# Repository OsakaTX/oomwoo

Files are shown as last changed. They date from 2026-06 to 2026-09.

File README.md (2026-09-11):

<div align="center">

# OOMWOO

*Open-source robot vacuum you build yourself*

Clean well · Hackable · Raspberry Pi · 3D printed · Local / No cloud required · Home Assistant · Arduino · ROS2 · ESP32




</div>

OOMWOO is an *open-source home robot vacuum* you can build yourself, built using
Raspberry Pi, 3D-printing, Home Assistant, Arduino and ROS2. It uses an
affordable 2D LiDAR to map your home and navigate on its own. Local, no
cloud required for regular functionality, no vendor lock-in. Follow us building in public
[Discord](https://discord.gg/3y2JKz5T25) | [X](https://x.com/@0OMWO0) | [Instagram](https://www.instagram.com/oomw0o/) | [Facebook](https://www.facebook.com/profile.php?id=61591466775035) | [Reddit](https://www.reddit.com/r/oomwoo/) | [newsletter](https://stats.sender.net/forms/bo2rAK/view) | [YouTube](https://www.youtube.com/@makerspet) | [oomwoo.com](https://oomwoo.com/) | [Tutorials](https://makerspet.com/learn/)

> Early [build instructions](docs/BUILD_INSTRUCTIONS.md) will be available in Fall 2026.

Reference design images - this is approximately how the finished design will look:

Reference robot vacuum cleaner top
Reference robot vacuum cleaner bottom
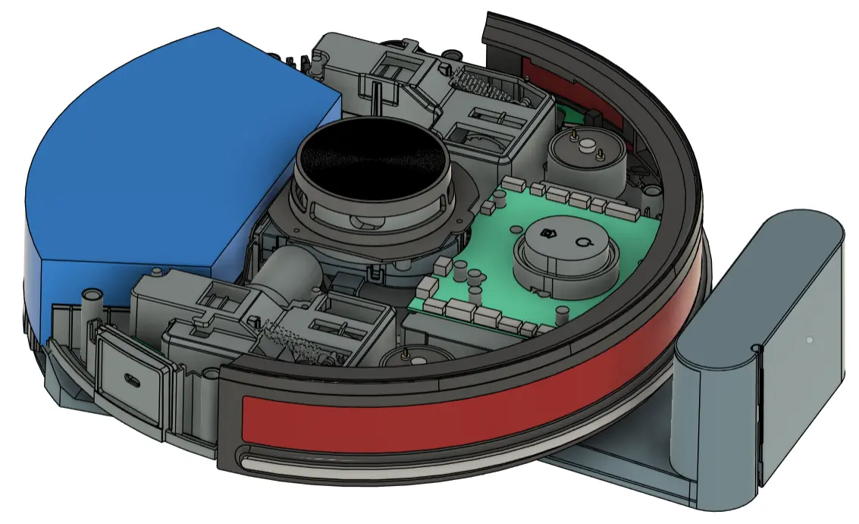
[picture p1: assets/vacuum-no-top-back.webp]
Reference robot vacuum cleaner - top cover removed


## Goals

- Affordable, fully open hardware, software and firmware
- Home appliance product quality - not a throwaway build
- Easy to build, with step-by-step zero-to-hero instructions
- 2D LiDAR mapping and autonomous navigation (ROS2 / Nav2)
- Native Home Assistant integration for local control
- 3D-printable, documented, and hackable chassis
- Buildable from parts you source yourself
- Local, no cloud required for regular functionality
- Optional extra functionality when connected cloud
- Apps on top of ROS2 to customize vacuum operation
- Stretch goal: App store
- Stretch goal: LeRobot integration, OpenClaw

*v0 target: bare-bones build:*

- 3D-printed chassis ([browse](https://github.com/makerspet/oomwoo-install))
- ROS2 Gazebo sim ([install](https://github.com/makerspet/oomwoo-install))
- Basic cleaning, mapping
- Raspberry Pi CM4/CM5 running ROS2 ([install](https://github.com/makerspet/oomwoo-install))

Open Source Deliverables:

- [x] [Software development environment](https://github.com/makerspet/oomwoo-install), robot [description package](https://github.com/makerspet/oomwoo-one/) and [tutorials](https://makerspet.com/blog/simulate-oomwoo-one-robot-vacuum-in-gazebo-with-ros-2/) (ROS2)
- [x] Placeholder real [vacuum cleaner](https://github.com/makerspet/proscenic-m6pro) and [tutorials](https://makerspet.com/blog/tutorial-connect-robot-vacuum-cleaner-to-ros-2-proscenic-m6-pro/) (temporary while OOMWOO is being designed)
- [x] [Bill of materials (BoM)](BOM.md) (rough version available)
- [x] 3D-scanned [sourced parts](https://github.com/makerspet/oomwoo-one-cad/tree/main/lib)
- [ ] 3D-printable [files](https://github.com/makerspet/oomwoo-one-cad)
- [ ] Raspberry Pi [software](https://github.com/makerspet/oomwoo-install)
- [ ] Motor drivers, sensors [PCB boards](https://github.com/makerspet/oomwoo-pcb)
- [ ] I/O PCB [firmware](https://github.com/makerspet/oomwoo-io-firmware)
- [ ] Build, setup, bringup and troubleshooting [instructions](docs/BUILD_INSTRUCTIONS.md)
- [ ] Demo video(s)

## Contributing

Would you like to contribute? See [CONTRIBUTING](docs/CONTRIBUTING.md) for the full guide.

OOMWOO is organized to built by the community, massively *in parallel*.
The vacuum and its software are subdivided into [modules](contributions/README.md), listed on the RFC board.

A volunteer picks whatever module she wants and works on it whenever she wants.
For *code and simulation* modules she builds her package in her *own repo* and sends
a short PR *linking* it from the module; for *docs and specs* she contributes files
in-tree under `contributions/module-name/<her-github-username>`. See
[CONTRIBUTING](docs/CONTRIBUTING.md) for how this works.

Multiple developers are welcome to work on the same module.
The best solution for each module surfaces over time, with the project master having the last call.

1. Pick a contribution from the [RFC board](contributions/README.md).
2. [Let us know](https://github.com/makerspet/oomwoo/discussions) you're working on it and your progress.
3. Check [ARCHITECTURE.md](docs/ARCHITECTURE.md) and
   [SOFTWARE_INTERFACES.md](docs/SOFTWARE_INTERFACES.md) for the system design
   and ROS2 interfaces.

## Requests for Contributions

Every module below is *actionable now* — build it against the Gazebo simulation
([oomwoo-one](https://github.com/makerspet/oomwoo-one)) or a real *placeholder robot*
(a [Proscenic M6 Pro connected to ROS2](https://makerspet.com/blog/tutorial-connect-robot-vacuum-cleaner-to-ros-2-proscenic-m6-pro/)),
until OOMWOO hardware is ready. Pick one, tell us in
[Discussions](https://github.com/makerspet/oomwoo/discussions), build it in your own
repo (docs and specs go in-tree), and send a short PR linking it from the module.

Every RFC — software, firmware, hardware and procurement — lives on the
**[RFC board](contributions/README.md)**, together with its current progress and
status. That board is the single source of truth, so this page links to it rather
than copying it: a second copy here only ever drifts out of date. Broadly:

- **Software & simulation** — cleaning, localization & navigation, perception, the Gazebo sim
- **Firmware & electronics** — STM32 I/O board firmware, the I/O + motor-driver PCB, the board interface
- **Mechanical & procurement** — brushes, blower fan, dust bin, part specs and STEP models

**[→ Browse the RFC board and pick a module](contributions/README.md)**

> Planned and on-hold modules (mechanical design, later-phase software) live in the
> [RFC backlog](docs/RFC_BACKLOG.md).

## Source code reference

- [OOMWOO ROS2 and Ubuntu installation](https://github.com/makerspet/oomwoo-install/) source code
- [OOMWOO ROS2 URDF package and config](https://github.com/makerspet/oomwoo_urdf/) source code
- [remakeai reference vacuum teardown](https://github.com/remakeai/vacuum_cleaner_teardown) — a consumer LiDAR vacuum with a basic dock and stationary mop.

## Related prior art

- [Valetudo](https://github.com/Hypfer/Valetudo) — cloud-free firmware replacement for commercial vacuums (local app-level control, not ROS2)
- [codetiger/VacuumTiger](https://github.com/codetiger/VacuumTiger) - 3irobotix CRL-200-based vacuum low-level control reverse engineered
- [kaiaai/LDS](https://github.com/kaiaai/LDS), [kaiaai/lds2d](https://github.com/kaiaai/lds2d) — open-source 2D LiDAR libraries (C++, Python) supporting 23+ LiDAR models
- [remakeai/vacuum_ros2_bridge](https://github.com/remakeai/vacuum_ros2_bridge) — ROS2 bridge for a 3irobotix CRL-200-based vacuum (Proscenic), full ROS2 control
- [Dennis Giese / robotinfo.dev](https://robotinfo.dev) — teardowns and rootability of commercial robot vacuums.
- [Build a ROS2/LiDAR robot crash course](https://makerspet.com/blog/build-arduino-self-driving-robot-video-instructions/) - watch this if you have no robotics experience
- [Open Mower](openmower.de) - open-source outdoor lawn mower
- [AlieksieievYurii/vacuum-cleaner](https://github.com/AlieksieievYurii/vacuum-cleaner) — a DIY 3D-printed robot vacuum (Raspberry
  Pi Zero W, gyroscope-based, Fusion 360, Android control app, no dock)

## User requirements &amp; Design research

Anecdotal prospective user requirements - collected mostly in [r/RobotVacuums](https://www.reddit.com/r/RobotVacuums/), [r/ROS](https://www.reddit.com/r/ROS/) and as [announcement post](https://makerspet.com/blog/building-an-open-source-robot-vacuum-meet-oomwoo/) comments:

- open-source
- 3D printed first
- cleans well, a first-class appliance, not a throwaway build
  - never gets stuck
  - hair tangle-free
  - modern capabilities - no legacy drag mop; dual-spinning rotary mop or better/roller
  - bagless
- hackable, DIY fixable, upgrade-able
  - examples: vacuum-only version, mop-only version
  - Raspberry Pi
  - Home Assistant integration
- operates without cloud
- later: ability to retrofit existing legacy vacuum cleaner robots

## About

The project name "OOMWOO" is a rotational ambigram - it reads the same flipped 180°, like the robot itself, roaming your floor in every direction.

The project is sponsored by makerspet.com and remake.ai. We are reusing their open-source solutions.
- If you'd rather skip the parts hunt, a kit (motors, PCB, brushes, gaskets, LiDAR) will be available at [makerspet.com](https://makerspet.com), from the same maker behind this project. The kit is a convenience, never a requirement. *Everything here stays open.*
- When we get to apps, [remake.ai](https://remake.ai) will be providing its robot apps platform and app store. Using the app store will be entirely optional. The vacuum will *always support cloud-free, local operation for regular functionality out-of-the-box*. 

## License

Code is released under the [Apache License 2.0](LICENSE).

Hardware design files, once added, to be released under an open hardware
license (TBD).

<!-- Self-hosted star history (auto-refreshed by .github/workflows/star-history.yml).
     No third-party embed / sealed token to expire. -->
<picture>
  <source media="(prefers-color-scheme: dark)" srcset=".github/assets/star-history-dark.svg" />
  <source media="(prefers-color-scheme: light)" srcset=".github/assets/star-history-light.svg" />
  OOMWOO star history
</picture>

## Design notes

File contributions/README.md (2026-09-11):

# OOMWOO Contributions — RFC board

Each folder here is a **Request for Contribution (RFC)** — a self-contained module
(software, firmware, hardware, or procurement) you can pick up and build. Submit
your work under `contributions/<rfc>/<your-github-username>/`. New here? Read
[CONTRIBUTING](../docs/CONTRIBUTING.md), and see the
[RFC lifecycle](../docs/CONTRIBUTING.md#rfc-lifecycle) for how RFCs progress and
retire.

**Status legend** — *Active:* `exploratory` → `ready to start work` /
`design-first` → `in progress`. *Retired* (closed to new contributions, but
**kept in place** for provenance): `completed` · `superseded` · `descoped` ·
`merged`.

**This board is canonical** for every RFC's status and progress. An RFC's own
README describes its scope and how to get started; where its `> Status —` line
disagrees with the row below, the row below wins. Update this board when you land
work.

**Progress** is a rough, self-reported percentage of the RFC's scope — a sense of
"how much is left", not a promise:
 nearly there ·
 under way ·
 barely started / open.

| RFC | What it is | Progress | Status |
|-----|---|:---:|---|
| [clean-and-map](clean-and-map) | First clean: coverage + SLAM + exploration |  | coverage meter + regression harness + drive-to-goal cleaning; coverage-while-mapping not started |
| [nav-localize](nav-localize) | Localization & navigation on a known map |  | AMCL to slam_toolbox (~3x accuracy), custom lost-detection + Cartographer-style global relocalizer (96/96 in sim), stress-tested; needs real-robot validation |
| [floor-care](floor-care) | Wall/edge following, surfaces, mop lift |  | LiDAR contour follower v1 follows walls and concave/convex boundaries (line-fit surface estimate replaced nearest-beam: 0.5 deg vs +-20 deg bearing error); bump-out wall clean; side ToF sensors, mop + FlexiArm modules modelled; loop-closure and bumper handoff still open |
| [cleaning-jobs](cleaning-jobs) | Cleaning modes, zones, job orchestration |  | ready to start work |
| [recovery-safety](recovery-safety) | Recovery behaviors & safety |  | lost-detect to relocalize recovery + one escape reflex; recovery ladder, e-stop, reporting open |
| [dock-cycle](dock-cycle) | Undock, dock, recharge & station services |  | dock mechanical design started; two docks modelled in sim (basic charging pad + auto-empty/mop-wash), manual undocking demoed; teardown, schematic, sensors + fans sourced; docking behaviours not started |
| [obstacle-avoidance](obstacle-avoidance) | Near-field camera + ToF avoidance |  | front ToF + stereo modelled in sim, transient-obstacle detection demoed, scan rays marked static/dynamic for downstream ML |
| [control-app](control-app) | Control app & UX |  | ready to start work (design track) |
| [live-robot-bringup](live-robot-bringup) | Live robot bring-up & validation |  | Proscenic M6 Pro to ROS2 tutorials; 3irobotix Delta-2C Pro LiDAR driver implemented and validated |
| [health-monitor](health-monitor) | Stack health monitor & software watchdog |  | design-first: contracts drafted, ready to start |
| [compute-benchmark](compute-benchmark) | Compute benchmark & memory reduction |  | tentatively fits 2 GB Pi CM4/CM5; an old smartphone is now a supported compute option (no Pi needed); repeatable Pi benchmark CLI + guide |
| [mcu-io-firmware](mcu-io-firmware) | MCU I/O board firmware (STM32G473) |  | host-tested framing/safety prototypes + simulated CPU/MCU loop; real STM32 HAL, motor and safety bring-up open |
| [io-board-interface](io-board-interface) | I/O board software interface |  | SPEC.md (GPIO/pinout contract) drafted; ROS2 bridge mapping + validation open |
| [urdf-gazebo-sim](urdf-gazebo-sim) | oomwoo URDF + Gazebo simulation |  | sim model essentially complete: full sensor suite, living-room + kitchen worlds, docks, GPU rendering |
| [mac-dev-env](mac-dev-env) | macOS (Apple Silicon) dev environment (pixi) |  | initial working pixi recipe (experimental) |
| [io-pcb](io-pcb) | I/O + motor-driver PCB (KiCad) |  | smartphone-as-compute option designed; schematic ~50% hand-checked (first review round); carpet sensor driver; drive wheels brought up on the bench; front + side sensor boards, watchdog + motor shutoff, charging dock; not validated, do not fabricate |
| [dust-bin](dust-bin) | Dust bin (mechanical module) |  | base port added to the chassis CAD; bin design still ahead |
| [vacuum-fan](vacuum-fan) | Blower fan assembly (mechanical module) |  | suction fan digitized to STEP, fans sourced and ordered, main fan brought up on the bench |
| [part-specs](part-specs) | Procure part specs & datasheets |  | drive-wheel and 4 suction-fan pinouts, voltages and no-load/stall currents confirmed by measurement; cliff/bumper/wheel pinouts reverse-engineered; dock fans, PSU, dock sensors, micro-switches, mop disk, VL6180 sourced |
| [source-3d-models](source-3d-models) | Source 3D models (STEP) for BOM parts |  | parts scanning mostly complete: battery, brushes, wheels, mop/FlexiArm, fan, carpet sensor, camera, switches |
| [stair-climbing](stair-climbing) | Multi-floor: stair climbing (drive-in exoskeleton) |  | exploratory, for later |
| [esp32-p4](esp32-p4) | ESP32-P4 experimental compute + safety track |  | exploratory, for later |

> **Two builds.** OOMWOO comes in a *basic* version (vacuum only, simple to
> assemble, charging-only dock) and a *full-featured* one (mop, auto-empty,
> extendable side brush). Some RFCs serve only the full build - mop lift in
> floor-care, the auto-empty dock in dock-cycle - so check which you are
> targeting before you start.

> **Core mechanical design is not an RFC.** The chassis, brushes, mop, wheel
> mounts and shell are designed in-house and tracked in
> [oomwoo-one-cad](https://github.com/makerspet/oomwoo-one-cad) — a tightly-coupled
> reference design is slow and messy to settle by consensus. Planned hardware
> modules are listed in the [RFC backlog](../docs/RFC_BACKLOG.md); a well-defined,
> standalone piece (a mount, a spec, a part model) graduates to an RFC here.

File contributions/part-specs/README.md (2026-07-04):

# Procure Part Specs & Datasheets for Sourced Components

We've already sourced candidate parts (see [BOM.md](../../BOM.md)). To design the I/O
board and firmware, *drive the motors and fans*, and build accurate mounts, we need each
part's detailed *electrical + mechanical specs* — pinouts, voltages, currents, encoder
PPR, torque, waveforms, etc. Vendors rarely publish these for vacuum sub-assemblies, so
contributors will *find datasheets, ask vendors, or safely reverse-engineer* them.

This is the *electrical/mechanical data* companion to
[source-3d-models](../source-3d-models) (which covers the *geometry*). No robotics
background needed — a multimeter, patience, and (for reverse-engineering) an oscilloscope go far.

Please check [BOM.md](../../BOM.md) and the [sourcing follow-along blog post](https://makerspet.com/blog/how-to-source-bom-for-oomwoo-open-source-vacuum-robot/)
for datasheets/specs already found.

## What we need, per part

### Drive wheel assembly (Roborock-family — see BOM)
- motor model; motor/assembly *datasheet* (if any)
- *encoder type + PPR* (pulses per revolution)
- *gearbox ratio*; *wheel diameter*
- rated + max motor *voltage*, *current* (no-load & stall), *torque*
- max / rated wheel *speed*
- *cable length(s)*; *connector models* (both ends); *full connector + motor pinouts*
- *wheel-drop sensor* model + pinout (these modules include one)
- signal *waveforms* (encoder channels, motor drive)
- assembly *weight*

### Suction fan / blower (several options sourced — see BOM)
- fan/motor model; *datasheet*
- rated *voltage, current, RPM*; *airflow* + *static pressure (Pa)*
- *how to drive it* — BLDC driver + control interface (PWM / tach / hall / 3-phase),
  soft-start / protection behaviour
- *connector model(s) + pinout*; cable length
- signal *waveforms*
- *weight*

### Caster / universal wheel assembly (Roomba-family — see BOM)
- model, dimensions, mounting, any embedded sensor, weight, datasheet

## Already found vs still missing 

*Found*
- *Fan datasheet (some options):* https://file.elecfans.com/web1/M00/CC/89/o4YBAF-ZOBKAQBvyADDMAglsvTw020.pdf
- *Nidec BLDC motors* (candidate fan motors — *bare motors, not the full suction assemblies*):
  [NCJ-20N Type-3](https://www.nidec.com/en/product/search/category/B101/M102/S100/NCJ-20N-Type-3/),
  [NCJ-20N Type-4](https://www.nidec.com/en/product/search/category/B101/M102/S100/NCJ-20N-Type-4/)
- *Driving the fans:* [ripinteer/fan_protector](https://github.com/ripinteer/fan_protector)
  — reference for driving / protecting the BLDC blower (from earlier project research)

*Still missing (help wanted)*
- Connector *pinouts* + cable lengths for wheels, fans, caster
- *Encoder type + PPR*, gearbox ratios, torque/current under load
- *Wheel-drop sensor* model + pinout
- Signal *waveforms* (encoder, motor/fan drive)
- Suction-*assembly*-level datasheets (we have some bare motors, not the assemblies)
- Weights; caster specs

## Reverse-engineering — only if specs can't be found, and SAFELY

If a spec isn't published, reverse-engineer it by opening an existing vacuum and probing.
*Safety first:*
- Don't do it unless you're qualified, experienced.
- Opening a vacuum usually *voids the warranty* and *can damage it* — accept that risk knowingly.
- *Secure / prop up the vacuum* so it can't scoot off the table or bench when the wheels or
  fan spin during testing (clamp it, or raise the wheels off the surface).
- Respect the *Li-ion battery* — don't short, pierce, or stress the pack; disconnect where sensible.
- Mind *pinch points and spinning parts* — keep fingers/hair clear of the impeller and brushes.
- Any *mains-connected* testing (e.g. a dock) — extra caution; isolate.
- Use a *multimeter + oscilloscope* to capture voltages, currents, and waveforms; trace and
  *label connector pinouts*; photograph everything.

*Legal:*
- By performing any work for this project including reverse engineering you agree to
  - wave liability, indemnify this project, the legal entity behind it (Remake AI Statutory Trust) and and its founder
  - contribute your work and results thereof, if any, as open-source, to be published under Apache 2.0 license

## Submit

A PR to `contributions/part-specs/<your-github-username>/<part>/`:
- a spec sheet (markdown table) with everything you found
- any datasheets (PDF) and source links
- photos of connectors + labelled pinouts
- waveform captures where reverse-engineered
- provenance — which vendor / model / revision the data is from
- announce it in [Project Discussions](https://github.com/makerspet/oomwoo/discussions?discussions_q=)

## Acceptance criteria

- Spec sheet for a part (or a clearly-scoped subset)
- Datasheets / links where found
  - pinouts + waveforms where reverse-engineered when appropriate
- Provenance stated (part / vendor / revision)
- Verifiable by someone else with the same part
- TBD, expect criteria to evolve

The maintainer selects among compliant candidates using these criteria. Multiple attempts
are welcome and useful even if not selected — a non-selected spec sheet is still a valid
reference and a fallback.

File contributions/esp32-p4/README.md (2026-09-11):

# ESP32-P4 (experimental compute + safety track)

A home for **ESP32-P4** experiments on OOMWOO: can a ~$4 dual-core RISC-V MCU
with 32 MB in-package PSRAM run onboard 2D SLAM, and what safety architecture
would a P4-based robot need? This is an **alternative compute path**, deliberately
separate from the consumer ROS 2 profile — see
[compute-benchmark](../compute-benchmark) for the Pi 4 / CM4 onboard-ROS 2 work.

> **Status — exploratory.** A *bounded feasibility experiment*, not a committed
> direction. The goal is a measured yes/no, not a port. Develop against a
> recorded dataset and the official Espressif dev board; coordinate in
> [issue #18](https://github.com/makerspet/oomwoo/issues/18) and the
> [discussions](https://github.com/makerspet/oomwoo/discussions).

## Why P4 is interesting

- **Cheap and capable-ish.** ESP32-P4: dual 400 MHz RISC-V HP cores + a 40 MHz
  LP core, up to **32 MB in-package PSRAM**, ~**$4** including the PSRAM.
- **Storage + I/O.** UHS-I 4-lane SDIO (fast SD/eMMC — a large map could be paged
  into PSRAM by region), dedicated CSI camera and DSI display pins *outside* the
  GPIO range, and a hardware H.264 encoder (up to 1080p/30) that can consume the
  CSI stream with little CPU load.
- **Pairs with a radio coprocessor.** ESP32-C5/C6 for Wi-Fi/BLE and 802.15.4
  (Matter over Thread).

## Why it is *not* a drop-in for the consumer profile

- **No NPU.** Modern vacuums lean on an NPU for real-time camera-based obstacle
  avoidance / object recognition; the P4 has none. (It can run small NNs in
  software with AI-acceleration instructions — e.g. a pedestrian-detection demo —
  but that is not an NPU.) OOMWOO's current vision plan is **two OV5647 stereo
  NIR wide-FoV cameras** (stereo depth + object recognition) — exactly the
  real-time workload an NPU normally accelerates, so whether the P4 can carry it
  is an open question (below).
- **Not enough GPIO for the MCU role.** The base controller needs 50+ GPIO (see
  the tentative pin list in issue #18). A TCA9554-class I²C IO expander adds
  *slow* binary in/out only; PWM, encoders, and fast interfaces must stay on a
  real MCU.
- **PSRAM is not free RAM.** Espressif's docs note accesses larger than the cache
  fall back to PSRAM speed, and task stacks live in internal RAM by default — so
  both *capacity* and *effective real-time bandwidth* must be measured, not
  assumed.
- **Hackability.** OOMWOO declares ROS 2 support so SLAM/nav is hackable to
  ~1.3M ROS 2 users; a native ESP-IDF SLAM firmware is hackable to ESP32 firmware
  specialists only. A P4 SLAM firmware is an *option*, not the official path.

## The bounded experiment

Prove or disprove "P4 can run onboard 2D SLAM" with one apples-to-apples test —
**do not port ROS 2 / Nav2 first**:

1. **Record one dataset** — LiDAR (5 Hz) + odometry, from the sim or the
   [placeholder Proscenic M6 Pro](https://makerspet.com/blog/tutorial-connect-robot-vacuum-cleaner-to-ros-2-proscenic-m6-pro/).
2. **Replay it two ways** — Pi 4 / CM4 with `slam_toolbox`, and the P4 with a
   *minimal native ESP-IDF 2D SLAM* prototype.
3. **Measure** against a fixed budget:
   - **~200 ms per scan** (5 Hz, no scan dropping);
   - **closes the loop within 32 MB PSRAM** without pathological fragmentation;
   - effective PSRAM bandwidth under cache-miss fallback; internal-RAM stack
     headroom.
4. **Use the official [ESP32-P4X-Function-EV-Board]** so silicon + memory config
   are explicit. Note the **"X"**: the board uses the **ESP32-P4NRW32X** die,
   recommended for new designs; many 3rd-party boards ship the non-"X"
   (older-revision) part.

**Pass** → the P4 earns a deeper prototype. **Fail** → the same dataset gives a
useful lower bound and reinforces the micro-ROS / offboard *educational* profile
without speculation.

## Safety architecture (ADR — to be written)

A P4 is a high-level compute module; it must **not** be in the hard-stop chain.
The direction from the thread is a layered, fail-low design:

1. **External hardware gate / window watchdog** — the final motor-power cutoff.
   Motor enable defaults **OFF** and requires a valid *periodic* signal; the
   passive electrical state (external pull-down / latch) means **stop**, so an
   unpowered or reset system cannot authorize motion.
2. **STM32G473 base controller** (selected) — owns wheel/brush
   PWM, encoders, current sensing, bumper/cliff/wheel-drop, charging supervision,
   and deterministic stop. It services the hardware gate *only* while its full
   safety state is valid. These functions can't be replaced by a gate IC without
   recreating them as a large discrete circuit.
3. **ESP32-P4** — SLAM / navigation / high-level behavior. Its **LP core** may
   monitor an HP heartbeat in shared/LP SRAM and assert a dedicated fail-low
   **`P4_HEALTHY`** line (and reset the HP cores), improving diagnostics — but it
   is *optional* to the hard-stop chain and never issues motor commands.

Related, separate milestone — **OTA update of the safety MCU** (later, after the
hard-stop and base-control firmware are bench-validated): the P4 can drive
`BOOT0` / `nRESET` into the STM32 factory ROM bootloader (AN2606 / AN3155 USART,
or USB DFU), so end users need no ST-Link or STM32 SDK. It must be gated by a
signed, version-checked, immutable STM32 boot stage; motors + charging forced OFF
throughout; dual-bank staging with rollback; and the P4 must not be able to
bypass signature verification. `esp-serial-flasher` is useful host/target prior
art but speaks Espressif ROM protocols, so it needs a separate STM32 backend.

## Open questions

- **Can the P4 perform real-time obstacle avoidance?** OOMWOO plans **two OV5647
  stereo NIR wide-FoV cameras** — stereo depth + object recognition at frame
  rate is the workload that normally needs an NPU/SoC. Can the P4's dual RISC-V
  cores + software AI-acceleration path meet it, or does obstacle avoidance stay
  off the P4 (host-side, or a separate accelerator)? Two OV5647s also need two
  CSI streams (dual-camera interface or a mux) — worth confirming on the P4X.
- Does a minimal native ESP-IDF SLAM meet the 200 ms / 32 MB budget at all?
- Is the LP core enough isolation, or is a dedicated hardware-gate IC still
  required as the final cutoff? (Leaning: keep the external gate regardless.)
- The current drive wheels are brushed DC motors controlled by STM32-owned
  H-bridges. The P4 must never run wheel PWM/H-bridge control or become part of the
  motor-stop path; its loss only removes high-level commands, while the STM32 and
  external watchdog force the safe state.

## Request for contribution

Add your work under your GitHub username:

```text
contributions/esp32-p4/<your-github-username>/
```

Keep native-SLAM prototypes, board bring-up notes, measurements, and the safety
ADR here. Coordinate scope in
[issue #18](https://github.com/makerspet/oomwoo/issues/18) so tracks don't overlap
with [compute-benchmark](../compute-benchmark),
[recovery-safety](../recovery-safety), or the I/O board work
([io-board-interface](../io-board-interface), [mcu-io-firmware](../mcu-io-firmware)).

[ESP32-P4X-Function-EV-Board]: https://docs.espressif.com/projects/esp-dev-kits/en/latest/esp32p4/esp32-p4x-function-ev-board/index.html

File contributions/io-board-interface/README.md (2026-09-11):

# I/O Board Software Interface

The I/O board is where OOMWOO's ROS2 software meets the real robot: wheel
drivers, cleaning motors, cliff sensors, bumper sensors, dock sensing, power
state, battery charging, and the MCU watchdog.

This contribution area is for the CPU-to-MCU software contract that sits between
the Raspberry Pi Compute Module and the STM32 I/O board firmware.

## Why this matters

The hardware can move quickly only if the firmware and ROS2 work have a stable
interface to build against. The goal is to define the contract before the board
is fully frozen:

- which signals are owned by the MCU vs the CPU
- what commands the CPU can send to the MCU
- what telemetry the MCU publishes back
- what always stays safety-critical and independent of Linux/ROS2
- how the ROS2 hardware bridge maps serial frames into standard ROS topics
- how to validate the contract in simulation, with loopback tests, then on real
  hardware

## Scope

Included:

- CPU-to-MCU serial protocol proposals
- ROS2 topic/service/action mapping for the hardware bridge
- safety and watchdog behavior
- signal ownership tables tied back to the I/O board schematic and part specs
- simulators, parsers, replay tools, and tests that make the protocol
  reproducible

Not included:

- final STM32 firmware implementation
- final PCB layout decisions
- Linux kernel drivers
- app/cloud/Home Assistant UI

## References

- [I/O + motor-driver PCB RFC](../io-pcb)
- [I/O board repository](https://github.com/makerspet/oomwoo-pcb)
- [Architecture: CPU/MCU split](../../docs/ARCHITECTURE.md)
- [ROS2 software interfaces](../../docs/SOFTWARE_INTERFACES.md)
- [Part specs](../part-specs)

## Submit

A PR to `contributions/io-board-interface/<your-github-username>/` should include:

- a short README explaining the proposed contract
- protocol docs or schemas
- a mapping from hardware signals to ROS2 topics/services
- testable tooling where possible
- known open decisions that need maintainer or PCB-designer input

## Acceptance criteria

- The contract is versioned and can evolve without breaking old frames silently.
- Stale motion commands fail safe.
- MCU-owned safety events do not depend on ROS2 being alive.
- Message rates and payload sizes are realistic for the chosen serial link.
- The proposal links back to current hardware references and calls out conflicts
  instead of hiding them.
- At least the framing/parser pieces are testable without hardware.

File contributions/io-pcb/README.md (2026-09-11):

# I/O + Motor-Driver PCB (hardware / KiCad)

The custom [I/O board](https://github.com/makerspet/oomwoo-pcb) that
connects every OOMWOO motor and sensor to the SBC: an STM32 MCU,
motor drivers, sensor front-ends, and battery charging on one PCB. Proposed
software-interface contract: the MCU runs safety-critical firmware and talks to
the CM4/CM5 CPU over a custom serial / USB link.

> *Draft design basis:* OOMWOO v1 uses a *CM4/CM5-style CPU module* for ROS2, Nav2, SLAM,
> so this board is an *I/O + power carrier* — no soldered application processor on it. There is a
> starting-point Kicad schematic and [SPEC.md](https://github.com/makerspet/oomwoo-pcb/blob/main/docs/SPEC.md).

# References

- *Board spec (authoritative, most up-to-date)* —
  [oomwoo-pcb](https://github.com/makerspet/oomwoo-pcb) ·
  [SPEC.md](https://github.com/makerspet/oomwoo-pcb/blob/main/docs/SPEC.md).
  The current MCU (**STM32G473VCT6**), motors, sensors, charging, and GPIO budget live here;
  this RFC is the request-for-contribution, the SPEC is the truth.
- *MCU firmware* — [mcu-io-firmware RFC](../mcu-io-firmware) ·
  [oomwoo-io-firmware](https://github.com/makerspet/oomwoo-io-firmware).
- *Starting-point schematic (PDF)* —
  [makerspet/oomwoo-pcb](https://github.com/makerspet/oomwoo-pcb/blob/main/docs/oomwoo-io-board-RK3562-schematic.pdf).
  An STM32G070 reference (Apache-2.0, *unvalidated* — a starting point, not a proven
  design). Trim it down as described below.
- *Current I/O board repository* —
  [makerspet/oomwoo-pcb](https://github.com/makerspet/oomwoo-pcb), including
  KiCad files and the evolving [SPEC.md](https://github.com/makerspet/oomwoo-pcb/blob/main/docs/SPEC.md).
- *CPU/MCU software interface* —
  [io-board-interface](../io-board-interface) drafts the custom serial contract, ROS2 bridge
  mapping, watchdog behavior, and hardware/software decision ledger.
- *Drive-wheel connector pinout* —
  [AlieksieievYurii vacuum-cleaner motherboard schematic](https://raw.githubusercontent.com/AlieksieievYurii/vacuum-cleaner/2bd7cf7f9af3ae9040373f667bab83e2e57c26b7/motherboard/circuit-pcb/SCHEMATIC_motherboard.svg)
  shows the drive-wheel assembly connectors: *JST PH2.0, 6-pin* —

  | Pin | Signal |
  |---|---|
  | 1 | MOT+ |
  | 2 | MOT- |
  | 3 | HALL_SPEED |
  | 4 | HALL_DIR |
  | 5 | +5V |
  | 6 | GND |

  Verify against the *sourced* Roborock-family wheel module before layout — a submission in
  [part-specs](../part-specs) describes a variant with extra wheel-drop / limit-switch pins,
  while the current OOMWOO I/O board schematic uses a board-side 5-pin signal connector with
  the H-bridge on the I/O board. Confirm the final connector and harness before layout.
- [part-specs](../part-specs) — connector pinouts, encoder PPR, and datasheets for the sourced parts.
- [design-document.md](../../docs/design-document.md) — the I/O-board section (MCU, pin budget,
  offloading the fan to an external ESC, etc.).
- [BOM.md](../../BOM.md) — the sourced parts this board must drive.
- [Project discussions](https://github.com/makerspet/oomwoo/discussions?discussions_q=) · [Discord](https://discord.gg/3y2JKz5T25)

# Request for Contribution — Instructions

Deliver a *KiCad schematic* derived from the reference PDF, trimmed to the I/O side and
updated for OOMWOO, then *hold for review before PCB layout*.

- *Remove the Rockchip subsystem entirely* — the RK3562 SoC and everything that exists only
  to support it: *LPDDR4 DRAM, eMMC, the SoC PMIC / SoC-specific power rails (VCCIO, PMU / OSC
  / PLL), the DDR PHY, the USB / PCIe PHY, and the SoC's MIPI camera interface*. Heavy compute
  and the camera interfaces now come from the *CM4/CM5 module* (whose socket this board adds) —
  the board routes MIPI CSI camera connectors off that socket (see [SPEC](https://github.com/makerspet/oomwoo-pcb/blob/main/docs/SPEC.md)),
  not off a removed SoC.
- *Remove the WiFi / BT module* (AP6256) — WiFi/BT comes from the compute module, or is added
  on the carrier (M.2 / USB) for modules without onboard WiFi (see SPEC).
- *Add a CM4/CM5 socket + support* (adapt the official Raspberry Pi CM4/CM5 IO-board designs)
  so the board is a *carrier* for the compute module; see the [SPEC](https://github.com/makerspet/oomwoo-pcb/blob/main/docs/SPEC.md).
- *Keep and convert to KiCad the I/O side:*
  - *STM32G473VCT6* MCU + support (clock, decoupling, debug / boot, the custom-serial link to the CPU)
  - *motor drivers* — drive wheels (×2), main brush, side brush, water pump, mop lift / spin
    (if fitted); put the *suction fan on an external ESC* (one PWM line) to save MCU pins
  - *sensor front-ends* — cliff / anti-fall IR, docking IR + bumper, side-proximity IR, bumper
    switches, IMU, LiDAR interface, multizone ToF, ultrasonic carpet sensor
  - *battery charging + protection / BMS*, and the board power rails that feed the STM32 /
    sensors / motors (keep these; remove only the SoC-specific rails)
  - speaker + amp, mic, buttons, LEDs
- *Move the battery from 3S to 4S* — OOMWOO targets *~14.8 V* (see [BOM.md](../../BOM.md)). The
  reference appears to be 3S; update the pack, the charge-IC configuration, the protection, and
  any cell-count-dependent dividers / thresholds to *4S*.
- *Reconcile the drive-wheel connectors* with the sourced wheel module and the current
  OOMWOO I/O board KiCad reference before layout; document the final board-side connector,
  harness, motor-power path, encoder pins, and wheel-drop handling.
- assume battery Xiaomi/Roborock/Dreame BRR-2P4S-5200
- *Convert the kept design to KiCad* (from Altium); keep a clean, readable, hierarchical schematic.
- *Hold here for review.* Deliver the trimmed, 4S, KiCad *schematic* and stop — the maintainer
  reviews before anyone starts PCB layout / manufacturing.
- *Submit* a PR to `contributions/io-pcb/<your-github-username>/` with the KiCad project, a short
  sub-BoM, and notes; announce it in [Project Discussions](https://github.com/makerspet/oomwoo/discussions?discussions_q=).
- iterate with review
- TBD, expect the RFC to evolve

## Acceptance criteria (schematic-hold milestone)

- The *entire Rockchip subsystem* (SoC, DRAM, eMMC, PMIC / VCCIO / PMU / PLL, DDR + USB/PCIe
  PHY, MIPI camera) and the *WiFi / BT module* are removed.
- The *kept blocks* (STM32G473, motor drivers, sensor front-ends, battery charging, audio,
  buttons / LEDs, the CM4/CM5 socket + support, and the custom-serial CPU link) are present,
  correct, and complete in *KiCad*.
- Battery as specified
- Drive-wheel connectors are reconciled with the current KiCad reference and part-specs,
  including motor-power path, encoder pins, and wheel-drop handling.
- Delivered as a buildable *KiCad project*; *ERC clean*; a sub-BoM and short design notes included.
- Stops at the reviewed *schematic* — no PCB layout yet.
- Documented and reproducible.
- TBD, expect criteria to evolve.

The maintainer intends to *accelerate* this module and may commission a contributor to do it;
community submissions are still welcome and reviewed the same way. The maintainer selects among
compliant candidates using these criteria — multiple attempts are welcome and useful even if
not selected.

## Appendix A. MCU GPIO budget

The GPIO budget is maintained in the board
[SPEC.md](https://github.com/makerspet/oomwoo-pcb/blob/main/docs/SPEC.md)
(authoritative, and it carries the open TODOs — e.g. the GPIO 36/46 bumper-label question).
It is **not duplicated here**, to avoid the two copies drifting apart.

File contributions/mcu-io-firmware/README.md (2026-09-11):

# MCU I/O Board Firmware (STM32G473 — Arduino + FreeRTOS)

The firmware that runs on the OOMWOO [I/O board](https://github.com/makerspet/oomwoo-pcb)
MCU. In OOMWOO's CPU/MCU split ([ARCHITECTURE.md §5.4](../../docs/ARCHITECTURE.md)),
the *CPU* (CM4/CM5-class module) runs ROS2/Nav2/SLAM, and the *MCU* on the I/O
board owns *motors, encoders, sensors, battery charging, and hard safety*. This
module is that MCU firmware. Its defining constraint: *safety must never depend on
Linux/ROS2* — and, per the architecture below, it must never depend on the friendly
Arduino layer either.

The full design lives in the firmware repo — this RFC is the request for
contribution and the acceptance bar.

> *Status — in progress.* Host-tested framing, safety-policy, simulator, and ROS2
> bridge work now exists, but real STM32 HAL, motor control, ISR integration, IWDG,
> charging, and measured cutoff times remain open. Build hardware milestones on a
> *Nucleo-G474* first; move to the real board when it is fabricated. Coordinate in
> the [firmware discussion](https://github.com/makerspet/oomwoo/discussions/49).

# Important References

- *Firmware repo + full spec* — [makerspet/oomwoo-io-firmware](https://github.com/makerspet/oomwoo-io-firmware).
  The repo README is the detailed architecture, peripheral map, and milestones; read it first.
- *Active implementations* — upstream framing bring-up
  [PR #2](https://github.com/makerspet/oomwoo-io-firmware/pull/2), ISR-owned CPU
  watchdog [PR #3](https://github.com/makerspet/oomwoo-io-firmware/pull/3), and
  [Creative-Dhanush's host-tested firmware/simulator](Creative-Dhanush) with its
  ROS2 bridge. These overlap at the protocol/policy layer; hardware integration
  and maintainer selection of the canonical upstream path are still open.
- *Board spec (authoritative)* — [oomwoo-pcb SPEC.md](https://github.com/makerspet/oomwoo-pcb/blob/main/docs/SPEC.md)
  — the motors, sensors, charging, and GPIO budget the firmware must serve (work in
  progress; note its open TODOs, e.g. the GPIO 36/46 bumper-label question).
- *CPU ↔ MCU serial contract* — [io-board-interface RFC](../io-board-interface) —
  the custom serial framing, command/telemetry set, and health/watchdog handshake.
- *System architecture* — [ARCHITECTURE.md §5.4](../../docs/ARCHITECTURE.md) — the CPU/MCU split and safety rationale.
- *Simulated MCU link* — the [oomwoo-install](https://github.com/makerspet/oomwoo-install)
  serial stub lets the CPU side be developed/tested before the board exists.
- [STM32duino](https://github.com/stm32duino/Arduino_Core_STM32) · [STM32FreeRTOS](https://github.com/stm32duino/STM32FreeRTOS)
- [Project discussions](https://github.com/makerspet/oomwoo/discussions?discussions_q=) · [Discord](https://discord.gg/3y2JKz5T25)

# The architecture, in one rule

Arduino-*or*-real-time-safety is a false choice; we get both by *layering*, so the
layer a contributor touches is not the layer that keeps the robot safe:

- *Layer 3 — Arduino (STM32duino) API:* the contributor-friendly surface where new
  behaviours, features, and peripheral bring-up happen.
- *Layer 2 — FreeRTOS tasks* (static allocation): comms, control, telemetry,
  charging, and safety supervisors; watchdog-fed, bounded reaction times.
- *Layer 1 — HAL/timer-ISR real-time core:* motor control, the hard-safety cutoffs,
  and the CPU watchdog. Maintainer-owned, safety-reviewed.

*The rule:* the safety and motor-control core is *structurally isolated* from the
Arduino layer — a bug or infinite loop in a contributor's sketch *cannot* defeat a
cliff-stop, an overcurrent cutoff, or the CPU watchdog, because those live in
interrupts and a hardware watchdog the upper layers can't starve.

# Request for Contribution — Instructions

Phased bring-up (details and the peripheral map are in the firmware repo README):

- *Blink + SWD + serial echo* on a G473 dev board.
- *CPU serial link* — implement the [io-board-interface](../io-board-interface)
  framing + health/watchdog handshake; loopback tests green.
- *One drive motor, closed loop* — H-bridge PWM + encoder capture + velocity PID in
  the real-time core (the pattern every other motor follows).
- *All actuators* — suction fan (BLDC + FG), main/side brush, LiDAR spin, water
  pump, mop motors/servos — each with current sense.
- *All sensors* — cliff / dock / side-proximity IR (ADC), bumpers, wheel-drop, IMU
  (SPI), current channels.
- *Safety layer* — ISR-level cliff/bumper/wheel-drop stop, per-motor overcurrent
  limiting, IWDG, CPU watchdog/reset; *measure and document* each cutoff's
  worst-case reaction time; include a hazard note.
- *Charging supervisor* — power-path charger control, 0.5C cap, input DPM, graceful
  "insufficient charger" handling.
- *Integration* — run end-to-end against the CPU (or the simulated MCU serial tool).
- Contribute in the firmware repo; announce progress in [Project Discussions](https://github.com/makerspet/oomwoo/discussions?discussions_q=).
- iterate with review
- TBD, expect the RFC to evolve

*Safety-critical code requires maintainer safety review before merge* (over-current,
thermal, short, mechanical pinch — include a hazard note).

## Acceptance criteria

Objective, measurable. Examples:
- *Deterministic real-time core* — measured, documented worst-case reaction time for
  each safety cutoff.
- *Safety is layer-independent* — a deliberately hung Arduino-level task must *not*
  defeat a cliff-stop, overcurrent cutoff, or the CPU watchdog; demonstrate it.
- *Implements the [io-board-interface](../io-board-interface) serial contract* —
  loopback + integration tested.
- *Every actuator and sensor exercised* on the bench, documented, reproducible by
  someone else.
- *Charging behaves per spec* — 0.5C cap held; graceful degradation on a weak charger.
- *Safety-critical code passed maintainer safety review* with a hazard note.
- TBD, expect criteria to evolve.

The maintainer selects among compliant candidates using these criteria. Multiple
attempts are welcome and useful even if not selected — a non-selected design is
still a valid learning exercise and a fallback.

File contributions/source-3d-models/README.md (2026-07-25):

# Source 3D Models (STEP) for Off-the-Shelf BOM Parts (procurement)

To design printed mounts and the chassis that *fit real sourced parts*, we need accurate
3D models (*STEP*) of the off-the-shelf components in the [BOM](../../BOM.md) — the
drive-wheel assembly, the suction fan/blower (several candidate models), the caster wheel,
the side-brush motor, and more. Manufacturers rarely publish these, so the community needs
to *obtain, measure, and model* them. Every printed mount and the chassis references this
geometry — see [ARCHITECTURE.md](../../docs/ARCHITECTURE.md) §5.2 (mechanical interface
standard). Missing models block or force guesswork on the mechanical modules.

This is a great *first contribution* for anyone with CAD skills and calipers — no
robotics or programming needed, and the modules can be modeled *in parallel*.

> *Please check the [STEP models library](https://github.com/makerspet/oomwoo-one-cad/tree/main/lib) before you pick a part.*
> STEP models live in the [makerspet/oomwoo-one-cad](https://github.com/makerspet/oomwoo-one-cad) repo, in the `lib` folder.

# Request for Contribution - Instructions

- *Pick a part* from the [BOM](../../BOM.md) and *claim it* in
  [Project Discussions](https://github.com/makerspet/oomwoo/discussions?discussions_q=) or
  [Discord](https://discord.gg/3y2JKz5T25) so two people don't model the same thing. Post progress too.
  - Please consider submitting a PR (pull request) to `makerspet/oomwoo` in `contributions/source-3d-models/<your-GitHub-username>/README.md`
  with a brief description of which part you have picked, relevant links (to your repo containing the part) and files if any.
- *Get an accurate model* — three paths:
  1. *Find an existing STEP* (manufacturer site, GrabCAD, etc.) and *verify it against the
     real part* (dimensions match). Fastest — but confirm it's the same model/revision.
  2. *Model it yourself*: order the exact part (AliExpress links are in the BOM), measure
     with calipers, optionally use a 3D scanner and build an accurate STEP.
  3. 3D scan the part, convert the mesh into a STEP file. As an example, I use Creality Raptor.
- *Capture the interface-relevant geometry* (external only — internal detail is not needed):
  - Overall *bounding envelope* (so it fits the chassis space / height budget)
  - *Mounting features*: holes, bosses, clips, bolt pattern — and their exact positions
  - *Functional interfaces*: axle/shaft position + axis, wheel contact plane, fan air
    inlet/outlet, connector / wire-exit locations
  - *Mating faces* where other modules attach
  - Note the *key overall dimensions*
- *Record provenance* — the exact vendor + link + which model/revision you measured. Parts
  vary between sellers and revisions; say which one this model represents.
- *Submit a PR* to `contributions/source-3d-models/<your-github-username>/<part-name>/`:
  - the *STEP* file (primary deliverable) + native CAD source (Fusion/SolidWorks/etc.) if you modeled it
  - a *photo* of the real part
  - the *source link* (AliExpress/vendor) and *key dimensions*
  - notes on tolerances and how you measured - if any
  - announce it in [Project Discussions](https://github.com/makerspet/oomwoo/discussions?discussions_q=)
- Iterate with review.
- TBD, expect the RFC to evolve.

(*) If you have a strong reason to model a different variant than the BOM lists, post your
rationale in [discussions](https://github.com/makerspet/oomwoo/discussions?discussions_q=) first.

## Acceptance criteria

Objective, measurable. Examples:
- Accurate *STEP* of the specified part — bounding envelope, mounting features, and
  functional interfaces match the measured real part (within a stated tolerance)
- Includes the *exact source link*, *key dimensions*, and a *photo* of the real part
  - Please make sure the model is licensed as open-source
- *Verifiable/reproducible* by someone else who buys the same part
- STEP provided (+ native CAD source if self-modeled)
- Documented well enough that a mount designer can build against it with confidence
- TBD, expect criteria to evolve

The maintainer selects among compliant candidates using these criteria. Multiple attempts
are welcome and useful even if not selected — models are swappable, and a non-selected
model is still a valid reference and a fallback.

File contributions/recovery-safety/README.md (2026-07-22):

# Recovery Behaviors & Safety (ROS2 package)

Keep the robot *unstuck and safe*. This package provides a *recovery ladder*
(back up, wiggle, shake free, rotate, nudge, clear costmap, try an alternate path),
*escalation* when a recovery attempt fails, and a final *pause-and-alert* state
when everything fails. It also covers *safety*: cliff / wheel-drop / pickup
detection, an e-stop, and *status / error reporting* so a human knows what
happened. Because the physical robot isn't built yet, this is a *Gazebo
simulation*; it is later re-validated on hardware in the
[live-robot-bringup RFC](../live-robot-bringup).

> *Status — ready to start work.* No need to wait for OOMWOO hardware — develop it in the
> Gazebo sim ([urdf-gazebo-sim](../urdf-gazebo-sim)) or on the real
> [placeholder Proscenic M6 Pro](https://makerspet.com/blog/tutorial-connect-robot-vacuum-cleaner-to-ros-2-proscenic-m6-pro/).
> Say so in the [discussions](https://github.com/makerspet/oomwoo/discussions) so we can coordinate.

# Design direction: reactive, contact-aware recovery (recommended)

Prior art is unanimous: real robot vacuums do **not** escape wedges with
navigation-stack recoveries. Nav2's `spin` / `backup` are *collision-averse* — they
check the costmap and refuse to move into the very cells the robot is wedged
against, so they stall exactly when needed (OOMWOO's own coverage planner already
documents *"spin/backup recoveries refuse to move there"*). A vacuum is
*contact-tolerant*: it has a bumper and is meant to touch walls and furniture. The
recovery it needs is a small **reactive, bumper-driven behavior layer** that runs
*open-loop and ignores the costmap*, layered **under** the planner and overriding it
while in contact (subsumption — Brooks, 1986). Coverage plans the open floor; this
handles near-obstacle. If it grows, this reactive layer can later be split into its
own `reactive-control` module.

**Proven escape heuristics** — a starting point from iRobot's *multi-mode coverage*
patents; tune the thresholds in sim. All are keyed on the *bumper pattern*, not the
costmap:

- *Wedge — bumper held.* If a bumper stays pressed for ~5 s, rotate **away from the
  pressed side** (a "panic turn") and retry; repeat until it releases. Back off and
  turn toward the free side — not a blind straight reverse.
- *Confined pocket — frequent bumps.* Track the running distance between bumps; when
  it drops below a threshold the robot is boxed in — switch to **bumper
  edge-following** (touch, small turns into-and-away) to worm out; below a lower
  threshold, panic-turn.
- *Stuck / wheels spinning — no bumps.* If the robot travels a long distance with no
  bump at all, assume it is high-centered / spinning — **spiral**, then panic-turn if
  still no contact.
- *Don't re-enter.* Mark the escaped pocket no-go so the sweep / gap-fill doesn't
  route straight back in (OOMWOO's coverage planner already does a version of this).

The simulated bumpers now publish (`/bumper_left|right/contact`), so this is
buildable and testable **headless today** — see
[oomwoo-one sim-bumpers](https://github.com/makerspet/oomwoo-one/blob/main/docs/sim-bumpers.md).
The same bumper-contact mechanism drives edge cleaning in [floor-care](../floor-care),
and stack-liveness safety lives in [health-monitor](../health-monitor).

# Important References
- [clean-and-map RFC](../clean-and-map) and [urdf-gazebo-sim RFC](../urdf-gazebo-sim) — the *bumper* (left / right / front) and any cliff / wheel-drop sensors this package reacts to.
- [nav-localize RFC](../nav-localize) — pickup / kidnap detection ties into relocalization.
- [ROS2 software interfaces](../../docs/SOFTWARE_INTERFACES.md) — shared topic/action/service contract for simulation-first modules.
- [OOMWOO ROS2 development](https://github.com/makerspet/oomwoo-install) — build OOMWOO ROS2 Docker image(s) with your packages.
- Nav2's behavior/recovery server can *compose* recoveries, but note its `spin` / `backup` are collision-averse (see *Design direction* above) — for wedges, prefer contact-aware escapes.
- *Prior art — the reactive layer everyone uses:* iRobot behavior-based vacuum control — [multi-mode coverage](https://image-ppubs.uspto.gov/dirsearch-public/print/downloadPdf/6809490) ([7173391](https://image-ppubs.uspto.gov/dirsearch-public/print/downloadPdf/7173391)) and [learned escape behaviors](https://image-ppubs.uspto.gov/dirsearch-public/print/downloadPdf/11656628); Brooks, *A Robust Layered Control System for a Mobile Robot* (subsumption, 1986).
- *Coverage-planning prior art:* [opennav_coverage](https://github.com/open-navigation/opennav_coverage) (Nav2 / Fields2Cover, open-field focused), Fraunhofer [ipa_room_exploration](https://medium.com/@jjbecomespheh/ros-coverage-path-planning-32ec97ce3c21), and online sensor-based coverage (BA\*, Morse decomposition). [VFH+](https://www.mdpi.com/2077-1312/12/3/412) is a contact-tolerant reactive alternative to costmap avoidance.
- [Project discussions](https://github.com/makerspet/oomwoo/discussions?discussions_q=)
- [Discord server](https://discord.gg/3y2JKz5T25)

# Request for Contribution - Instructions

- implement a *recovery ladder*
  - a configurable, ordered set of behaviors, e.g. *back up*, *wiggle / shake free*, *rotate in place*, *clear the costmap*, *nudge*, *try an alternate path*
  - pick the right recovery for the situation (wedged, bumper-jammed, no valid path, localization lost)
  - for *wedges*, prefer *contact-aware, open-loop* escapes (see *Design direction* above) over Nav2 `spin` / `backup`, which are collision-averse and stall in the wedge; start from the bumper-pattern escape heuristics and tune them in sim
  - post in [Project Discussions](https://github.com/makerspet/oomwoo/discussions?discussions_q=) to let everyone know you're working on it, and post your progress
- *escalation*
  - if behavior *N* fails, try *N+1*; track attempts per situation so the robot doesn't repeat a recovery forever
- *pause-and-alert*
  - when the whole ladder is exhausted, stop safely, publish a clear *error / status*, and wait for a human or a resume command — *never thrash*
- *safety sensors*
  - detect *cliffs*, *wheel drop*, *pickup / kidnap* (hand pickup detection to [nav-localize](../nav-localize)), and bumper jams; respond by stopping motors / entering a safe state
- *e-stop*
  - a software emergency stop that brings the robot to a safe state immediately
- *status & error reporting*
  - a structured robot-state / error topic, human-readable, suitable for Home Assistant, so a person knows *why* the robot paused
- test it well
  - induce wedged / stuck situations in sim: trap the robot, drop a dynamic obstacle onto it, place it at a cliff edge, lift it
  - verify the ladder runs, escalates, then pauses-and-reports; verify it never thrashes indefinitely
- regression tests (headless, CI-friendly)
  - recovery success rate across induced stuck scenarios
  - guaranteed termination — the robot always reaches *recovered* or *paused-and-reported*, never an infinite loop
  - safety responses fire on cliff / wheel-drop / pickup / e-stop
- submit a PR (pull request) to `contributions/recovery-safety/<your-github-username>/`
  - link to ROS2 package(s)
  - instructions, documentation - how to install, run, configure, troubleshoot, test results
  - videos of recovery, escalation, and pause-and-alert
  - announce your submission in [Project Discussions](https://github.com/makerspet/oomwoo/discussions?discussions_q=)
- iterate with review
- TBD, expect the RFC to evolve

## Acceptance criteria

Objective, measurable. Examples:
- A configurable *recovery ladder* runs the right behaviors for the situation and frees the robot in the large majority of induced stuck scenarios
- Recoveries *escalate* and are bounded — the robot never repeats a failed recovery forever
- When recovery is impossible, the robot *pauses safely and reports a clear error*, then resumes on command
- *Safety*: cliff, wheel-drop, pickup, and e-stop all bring the robot to a safe state
- *Status / error reporting* is structured and Home-Assistant-friendly
- *Regression tests* pass, including a guaranteed-termination check, runnable headless in CI
- Documented and reliably reproducible by someone else
- TBD, expect criteria to evolve

The maintainer selects among compliant candidates using these criteria. Multiple
attempts are welcome and useful even if not selected — modules are swappable, and
a non-selected design is still a valid learning exercise and a fallback.

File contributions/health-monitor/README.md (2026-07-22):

# Stack Health Monitor & Software Watchdog (ROS2)

The *soft-fault safety layer*: detect when the ROS2 stack — or any safety-critical
component — is no longer *alive and well*, and bring the robot to a safe state
through the MCU. It sits *above* the MCU's hard reflexes (cliff / bumper /
wheel-drop / overcurrent motor cutoffs, which stay independent in firmware) and
*below* the application. It is the thing that stops the robot when a critical node
*crashes*, *deadlocks*, or *was never brought up* — the cases the MCU's raw
CPU-liveness watchdog alone cannot see (the CPU is "alive", but the stack is not
actually driving safely).

The core idea: every safety-critical node publishes an *alive-and-well* heartbeat;
a *health aggregator* checks those against the set of components that are *supposed*
to be running for the current task; and only then does it emit a *single* "stack
healthy" heartbeat to the MCU. If any expected component goes stale or unhealthy,
the aggregate heartbeat stops and the MCU fails the robot safe.

> *Status — design-first, ready to start.* The contracts (heartbeat, roster, MCU
> behavior) can be designed and prototyped now in the Gazebo sim
> ([urdf-gazebo-sim](../urdf-gazebo-sim)) or on the placeholder Proscenic; the MCU
> side lands with [mcu-io-firmware](../mcu-io-firmware) /
> [io-board-interface](../io-board-interface). Say hi in the
> [discussions](https://github.com/makerspet/oomwoo/discussions) so we can coordinate.

# Why this, not "re-publish /cmd_vel"

A dead or hung controller must stop the robot. Re-publishing `/cmd_vel` and relying
on a drive-command timeout only covers *one* consumer and *one* failure. A stack
health monitor is more general — a fault *anywhere* in the critical set (localization,
costmap, the safety node itself) trips it — and it lets the MCU keep the *simplest*
drive semantics (hold the last setpoint; controllers send explicit stops at maneuver
ends), with **one** clean safety path instead of a timeout on every topic.

# Design sketch

- *Per-component heartbeat.* Each safety-critical node publishes a small
  `alive-and-well` message (node id, health level, stamp). Assert it *from the work
  path* — e.g. "I completed a control cycle / produced a scan" — **not** from a
  free-running timer. A timer keeps ticking even when the node's real loop has
  deadlocked, so a timer-based heartbeat can lie.
- *Expected roster.* The task launch (clean, map, dock, …) declares the set of
  *critical* components it brings up — published latched (`transient_local`) and
  re-posted on task transitions. Mark *critical* vs *advisory*: a dead logger or
  RViz must not stop the robot. The roster is what lets the aggregator notice a node
  that *never started* or *died completely* (a dead node simply stops publishing).
- *Health aggregator (the deadman).* Matches live heartbeats against the roster and
  emits the single MCU heartbeat only while *every* expected critical component is
  *fresh and well*. **Fail-safe by default:** withhold the heartbeat until the roster
  is known and the full set is confirmed healthy (an *arming* window). A useful
  consequence — the robot is physically immovable until the stack is confirmed up.
- *MCU side.* The MCU consumes the aggregate heartbeat as its stack watchdog (see
  [ARCHITECTURE.md](../../docs/ARCHITECTURE.md): the MCU asserts the CPU-reset line on
  missed health packets). Two-stage response: a brief miss → *soft-stop* motors
  (recoverable); a sustained miss → assert *CPU-reset*. The hard reflex layer
  (cliff / bumper / overcurrent ISR) is independent and always on.

# Important References

- [ARCHITECTURE.md](../../docs/ARCHITECTURE.md) — the CPU↔MCU link and the MCU-asserts-CPU-reset-on-missed-health-packets contract this feeds.
- [io-board-interface](../io-board-interface) and [mcu-io-firmware](../mcu-io-firmware) — the MCU heartbeat input, soft-stop, and CPU-reset behavior. Decide *here* what the MCU does with a *stale drive setpoint* (hold vs. drive-freshness timeout); with this monitor in place, "hold the last setpoint" is the simplest choice.
- [recovery-safety](../recovery-safety) — this removes the *safety* reason for the recovery node to re-publish `/cmd_vel`; recovery still sends explicit stops at the end of each maneuver.
- Nav2 `lifecycle_manager` + *bond* — an existing "expected roster (`node_names`) + liveness (the bond breaks when a managed node dies)" mechanism you can build on or feed from. Note: we run it with `bond_timeout: 0.0` in the sim because a slow sim clock false-trips it — liveness timeouts are *jitter-sensitive*, plan margins accordingly.
- `diagnostic_updater` / `diagnostic_aggregator` (`/diagnostics`) — the standard ROS2 way for a node to publish "alive and *well*". The deadman can consume it, but keep the final MCU-facing aggregator *tiny and auditable*.
- [SOFTWARE_INTERFACES.md](../../docs/SOFTWARE_INTERFACES.md) — where the heartbeat + roster + aggregate contract should be recorded.
- [Project discussions](https://github.com/makerspet/oomwoo/discussions?discussions_q=) · [Discord server](https://discord.gg/3y2JKz5T25)

# Request for Contribution - Instructions

- *Define the contracts* (design-first; record in [SOFTWARE_INTERFACES.md](../../docs/SOFTWARE_INTERFACES.md)):
  - the per-component *heartbeat* message + topic (id, health level, stamp) and the *heartbeat-from-work* rule
  - the *roster* message + topic (critical vs. advisory, latched, per-task) and how task launches publish it
  - the *aggregate MCU heartbeat* plus the *arming / fail-safe / recovery* states
- *Build the aggregator node* — roster match, freshness + health check, fail-safe default, arming window, single-heartbeat output. Keep it small and auditable.
- *Instrument a few critical nodes* to emit work-path heartbeats (start with the recovery/safety node and the controller); optionally bridge Nav2 *bond* / `/diagnostics` into the roster.
- *Pick timing* — component-rate < aggregator-rate < MCU-timeout, with margins that survive clock/load jitter; document the *detect-to-stop* budget versus robot speed (at vacuum speeds a sub-second budget is < 0.3 m).
- *Simulate the MCU side first* — a stand-in that consumes the aggregate heartbeat and soft-stops `/cmd_vel`, so the whole loop is testable headless before firmware exists; hand the behavior to [mcu-io-firmware](../mcu-io-firmware).
- post in [Project Discussions](https://github.com/makerspet/oomwoo/discussions?discussions_q=) to let everyone know you're working on it, and post your progress
- iterate with review; TBD, expect the RFC to evolve

## Acceptance criteria

- A written *heartbeat + roster + aggregate* contract in SOFTWARE_INTERFACES.md.
- An aggregator that, in sim, *stops the robot* when any expected critical node is
  killed / hung / missing, and *refuses to arm* until the full roster is healthy —
  demonstrated headless.
- *No false trips* under normal startup and under load / clock jitter.
- The hard MCU reflex layer stays independent — a bumper / cliff stop must not depend
  on this path.
- TBD, expect criteria to evolve.

The maintainer selects among compliant candidates using these criteria. Multiple
attempts are welcome and useful even if not selected — modules are swappable, and a
non-selected design is still a valid learning exercise and a fallback.

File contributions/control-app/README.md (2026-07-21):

# Control App & UX (design-first)

The app and UI a person actually touches to run their OOMWOO: start a clean, see
the map, set no-go zones, check on the robot, schedule. OOMWOO is *local-first and
cloud-free by design*, so the control app is too — it's a *client of the OOMWOO
ROS2 stack and Home Assistant*, not a phone-home service.

This module is *design-led*: it welcomes *designers* as much as coders. It runs in
two tracks — a *design track* that can start now, and a *build track* that follows
once the MVP scope and the robot's core behaviours settle.

> *Status — ready to start work (design track).* The robot's core (cleaning,
> navigation) is still being built, so the useful work *now* is *direction*:
> prioritise the feature set and concept the near-term control surface. Hold
> polished prototypes and the app build for far-future features until the scope and
> the robot behaviours land. Say hi in the
> [discussions](https://github.com/makerspet/oomwoo/discussions) so we can coordinate.

> *Grounding rule.* The app can only do what the robot exposes. Anchor every screen
> to a real capability in [SOFTWARE_INTERFACES.md](../../docs/SOFTWARE_INTERFACES.md)
> (and Home Assistant) and to a real user need — not to a feature that doesn't exist yet.

# Important References

- *[Valetudo](https://github.com/Hypfer/Valetudo)* — the closest existing example of
  what OOMWOO wants: a *local, cloud-free web UI* for (rooted) robot vacuums. Study
  its information architecture and interaction patterns (live map, zones, segments,
  go-to, settings) — the reference for a *privacy-respecting* control UX.
- *Consumer vacuum apps — learn from them without owning a robot.* The Roborock,
  Dreame, Ecovacs, and iRobot apps are worth studying for what works (map editing,
  room segmentation, zones / no-go, scheduling, multi-map) *and* what to avoid (ads,
  upsells, cloud lock-in, dark patterns). *You don't need to own a vacuum* — YouTube
  has plenty of *app/UI walkthroughs and reviews* demonstrating these flows (search
  e.g. "Roborock app tutorial", "Dreamehome app", "Ecovacs Home app"). Using one is
  better for real intuition, but watching is enough to learn the patterns.
- *Real user research (free)* — the OOMWOO Hacker News and Facebook threads have
  *hundreds of real users* saying what they love and hate (privacy / no-cloud,
  auto-empty, pet hair, edge cleaning, "brain-transplant my dead vacuum"). Mine these
  for genuine pain points instead of guessing.
- *Community feature-ideation board* — alfatreze's starting board:
  [Feature Ideation (Notion)](https://app.notion.com/p/Feature-Ideation-d5cd9e5c8eb840768ad98e989bbf7b70).
  A wide-net idea dump to prioritise from (a working board — decisions land in the
  project, see below).
- *[SOFTWARE_INTERFACES.md](../../docs/SOFTWARE_INTERFACES.md)* — the ROS2 topics /
  actions / state the app is a client of.
- *Home Assistant* — OOMWOO targets native HA integration; treat an HA dashboard as a
  first-class control surface, not an afterthought.
- [Project discussions](https://github.com/makerspet/oomwoo/discussions?discussions_q=) · [Discord](https://discord.gg/3y2JKz5T25)

# Request for Contribution — Instructions

*Design track (start here):*

- *Prioritise the feature set* — turn the community idea dump into a clear
  *MVP / v1 / later* structure (Must / Should / Could is plenty of rigour for now),
  grounded in what the robot exposes ([SOFTWARE_INTERFACES.md](../../docs/SOFTWARE_INTERFACES.md))
  and real user pain (the HN / Facebook threads).
- *Concept the MVP control surface* — the near-term screens that map to behaviours
  we're actually building: *start / stop / pause a clean, live map, robot status
  (battery, docked, stuck / needs-attention), teleop, no-go zones / virtual walls,
  basic scheduling*. Local-first; no mandatory cloud.
- *Design system / visual language* — a small, reusable, accessible design system
  (aligned with the OOMWOO brand) so the app and future screens stay consistent.
- *Aggregate community input in the open* — working boards (Notion / Figma / FigJam /
  Penpot) are welcome for ideation, but land the *prioritised set and decisions* in a
  *GitHub Discussion* (or here in this module) so the whole community can weigh in and
  it's part of the project record, not one account.
- post progress in [Project Discussions](https://github.com/makerspet/oomwoo/discussions?discussions_q=)

*Build track (later):*

- Implement the app once the MVP scope + robot behaviours settle — e.g. a *local web
  UI* (à la Valetudo), a *Home Assistant dashboard*, and/or a mobile client. Build
  against [SOFTWARE_INTERFACES.md](../../docs/SOFTWARE_INTERFACES.md); contribute in
  your own repo and link it (per [CONTRIBUTING](../../docs/CONTRIBUTING.md)).

- iterate with review
- TBD, expect the RFC to evolve

## Acceptance criteria

*Design milestone:*
- A *prioritised feature set* (MVP / v1 / later), grounded in SOFTWARE_INTERFACES +
  real user pain, and *reviewed by the community* (not siloed in one board).
- *MVP control-surface concepts* (user flows + wireframes) for the near-term
  behaviours, each mapping to a real ROS2 capability.
- *Local-first* — no mandatory cloud, consistent with OOMWOO's privacy DNA.
- A starter *design system / visual language*.
- Decisions recorded *in the project*.

*Build milestone (later):*
- A working app implementing the MVP control surface against the ROS2 stack /
  Home Assistant; documented and reproducible.

- TBD, expect criteria to evolve.

The maintainer selects among compliant candidates using these criteria. Multiple
attempts are welcome and useful even if not selected — modules are swappable, and a
non-selected design is still a valid learning exercise and a fallback.

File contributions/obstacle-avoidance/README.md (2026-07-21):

# Near-Field Obstacle Avoidance: camera + ToF (ROS2 package)

Stop the robot getting stuck on the things a 2D LiDAR *cannot see*. The turret
LiDAR is blind below its ~10 cm scan plane — cables, socks, shoes, pet bowls,
thresholds — which is the *top real-world complaint* about robot vacuums. This
package adds *near-field forward perception* from a *front camera* and/or a
*multizone Time-of-Flight (ToF) sensor*, detects obstacles in front of the robot,
and publishes them so navigation and recovery can react. Because the physical
robot isn't built yet, the *software* is developed in a *Gazebo simulation*; it is
later re-validated on hardware in the [live-robot-bringup RFC](../live-robot-bringup).

> *Status — ready to start work (forward-looking / experimental).* This is the
> v2 "never gets stuck" direction, not a v1 promise — the v1 fallback for low
> obstacles is the *bumper* ([recovery-safety](../recovery-safety)). Develop the
> software in the Gazebo sim ([urdf-gazebo-sim](../urdf-gazebo-sim)); say so in the
> [discussions](https://github.com/makerspet/oomwoo/discussions) so we can coordinate.

> *Two tracks in this RFC.* (1) A *software* track — the sensor-agnostic ROS2
> package that detects and publishes obstacles (sim-first). (2) A *hardware* track —
> building and benchmarking the candidate front-depth sensors to decide which one
> the robot ships. They meet at a shared obstacle interface: the software must not
> care *which* sensor produced the depth/obstacle data.

# Important References

- [recovery-safety RFC](../recovery-safety) — the v1 bumper-based reaction this augments; a detected obstacle should feed the recovery/avoidance ladder.
- [clean-and-map RFC](../clean-and-map) / [cleaning-jobs RFC](../cleaning-jobs) — coverage/nav that consumes the obstacle signal to slow, steer, or replan.
- [urdf-gazebo-sim RFC](../urdf-gazebo-sim) — robot URDF; this package needs a *front camera* and a *front ToF* modeled.
- [ROS2 software interfaces](../../docs/SOFTWARE_INTERFACES.md) — shared topic/action/service contract for simulation-first modules.
- [OOMWOO ROS2 development](https://github.com/makerspet/oomwoo-install) — build OOMWOO ROS2 Docker image(s) with your packages.
- [Project discussions](https://github.com/makerspet/oomwoo/discussions?discussions_q=) · [Discord](https://discord.gg/3y2JKz5T25)

# Front sensor — three candidate approaches (under evaluation)

The 2D LiDAR handles 360° mapping/localization. This module fills the *below-LiDAR,
forward* gap, which needs a **wide horizontal FoV (target ≥120°)** so obstacles
across the robot's path — not just dead ahead — are seen. There are three
candidates; **which one (or combination) ships is exactly what the hardware track
below is meant to decide.**

### A. Stereo depth — 2× OV5647 + IR pattern illuminator

- Two rolling-shutter cameras with **wide lenses (target 120–160° horizontal)**,
  computing dense depth by disparity; doubles as the semantic camera.
- **Textureless surfaces** (blank walls/floors) give stereo no features → pair it
  with an **840 nm random-dot pattern illuminator** (eye-safe *LED* + engineered
  diffuser or a printed random-dot mask; **not** a laser projector — avoids the
  Class-1/DOE-interlock burden). Short range is fine; that's all we need.
- **Sync is mandatory and not automatic**: two *independent* OV5647 on the two CSI
  ports free-run and won't genlock. Drive frame-sync over a **shared I²C control
  line, broadcasting a single write** to both sensors (+ FREX/snapshot mode). Naive
  "2× cameras" stereo is a known trap.
- Cost: uses **both CM4/CM5 CSI lanes** and real depth-matching compute (competes
  with SLAM/NPU on the Pi). Widest FoV, richest data.

### B. Multizone ToF — 2× VL53L7CX/CH, angled ±30°

- Each VL53L7CX/CH is an 8×8 multizone ToF with **~60° horizontal FoV** (the "90°"
  in the datasheet is *diagonal*). Place **two side-by-side, one aimed 30° left, one
  30° right → ~120° horizontal total.**
- **I²C, not CSI** → frees both camera lanes, near-zero compute (128 range zones,
  not image frames). **Class-1 eye-safe** (VCSEL sealed in the module). **Works in
  total darkness and on textureless/blank surfaces** — no illuminator, no pattern.
- Sourcing: bare **VL53L7CX/CH ~$5.50 at DigiKey**; order **unpopulated carrier
  PCBs**, populate and **reflow at home**. ⚠️ It's an **optical LGA** — keep flux
  off the aperture and follow ST's reflow profile (this part has a cover-glass;
  no-clean, no post-wash near the window).
- Trade-off: coarse (8×8 per sensor) — great for *"something is there, this far,
  this tall"*, poor at *shape/contour* and no semantics.

### C. Both combined

- ToF for reliable, dark/blank-proof **geometry**; stereo (or a single wide camera)
  for **wide semantics + dense shape**. Fuse them. Most capable, most cost/compute.

> *Sim modeling.* Gazebo has no VL53L7CX model — approximate a multizone ToF with a
> *low-resolution depth camera* or a small *ray grid* over the same FoV/zones, and
> the camera(s) with standard Gazebo camera sensors. Add sensors *inside your
> submission* and propose folding the stable ones back into
> [urdf-gazebo-sim](../urdf-gazebo-sim) later — please don't rewrite that RFC.

# Hardware track — build & benchmark the candidates

**Goal:** determine, on real obstacles, which of **A / B / C** best detects the
near-field, below-LiDAR obstacles — and whether one suffices *alone* or they must
be *combined*. This produces a data-backed sensor decision for the BOM.

### Build notes

- **B (2× ToF)** is the cheapest, lowest-risk build (I²C, no CSI, no illuminator,
  eye-safe, dark/blank-proof) — a natural *first* thing to characterize. Mount two
  carriers at ±30°, verify the seam/overlap near boresight, and publish combined
  zones.
- **A (stereo)** needs the sync harness (shared-I²C broadcast + FREX) and the
  **840 nm illuminator**; validate *passive* stereo first (textured obstacles) then
  measure how much the pattern illuminator helps on blank floors/walls.
- Whichever is characterized, publish the **same obstacle interface** (below) so the
  software track and Nav2 don't care which sensor won.

### Test protocol — obstacles (primary)

Model the obstacle set on **[how Vacuum Wars tests obstacle avoidance](https://vacuumwars.com/how-vacuum-wars-tests-robot-vacuums/)**
so results are comparable to commercial robots:

- ~**24 objects** across categories, scored **1 point per object avoided** (their
  scale), run at max sensitivity. Categories include **cords/cables, socks, shoes,
  simulated pet waste**, plus a **"torture" pass** mixing everything — deliberately
  including **objects unlikely to be in any trained image library** (this is where
  ToF's geometry-only detection can *beat* a camera that relies on recognition).
- Include their **rug cases**: a *solid-color rug with same-color items* and a
  *patterned rug with a contrasting item* — both stress depth/segmentation.
- Add OOMWOO-specific cases the reviews under-cover: a **cable lying flat**, a **~2 cm
  threshold**, and a **cliff/edge** in-frame.
- **Run every case in two lighting conditions — normal light and full darkness** —
  and on **≥2 floor types**. Darkness and blank surfaces are the decisive
  differentiators: ToF is lighting-independent; stereo needs the IR illuminator and
  texture.

### Test protocol — object recognition (secondary)

Lower priority than raw obstacle avoidance. Where a camera is present, measure
**classification accuracy** for the categories above (feeds semantic behaviors like
"never smear pet waste — stop and alert"). A miss here should still *avoid* the
object as an unknown obstacle; recognition only changes the *reaction*, not the
*detection*.

### Metrics to report (per approach)

- **Detection / avoidance rate** per obstacle type (true-positive %), and the
  aggregate Vacuum-Wars-style score (/24).
- **False-positive rate** on clear floor (does normal cleaning get disrupted?).
- **Min detection distance & reaction distance**; blind spots / FoV coverage across
  the ≥120° target (map the seam between the two ToFs / stereo edges).
- **Darkness** and **blank-surface** performance deltas vs. normal.
- **Depth accuracy** vs. ground truth; **latency / frame rate**.
- **Pi compute load** (CPU/NPU %) — a real cost for stereo.
- **Integration cost**: CSI lanes used, power, BOM $, build/reflow difficulty.

### Decision framework

Pick the approach that clears the acceptance criteria at the **lowest cost +
compute + integration burden**. Expected shape of the answer: **B (2× ToF) as the
robust, cheap, dark/blank-proof geometry baseline**; add **A (camera/stereo)** if
semantic recognition or shape/contour proves necessary → i.e. **C** for the premium
tier. Let the data decide; publish it so the choice is reviewable.

# ROS2 obstacle interface (shared by both tracks)

Whichever sensor is used, publish obstacles in `base_link`: **distance + bearing /
coordinates**, plus `object_type` (`unknown` in Phase 1; typed in Phase 2), and/or
a `PointCloud2` / `Range`-grid the nav stack can consume as a costmap layer. Feed
[recovery-safety](../recovery-safety) / navigation — *coordinate the interface
rather than driving `cmd_vel` directly* where a nav layer owns it.

# Request for Contribution — Instructions

- *add the sensors to the sim robot*
  - front camera (image topic) and front ToF (zone/range topic), co-located and
    calibrated to a shared front frame
  - post in [Project Discussions](https://github.com/makerspet/oomwoo/discussions?discussions_q=) to let everyone know you're working on it, and post progress
- *Phase 1 — detect, don't classify*
  - from the ToF (primary) and camera, detect *any* obstacle in the forward
    near-field and publish it: *distance + bearing / coordinates in `base_link`*,
    with *object type = unknown*. Free-space vs blocked is enough to be useful.
  - the point is coverage of the *below-LiDAR* zone the 2D scan misses
- *Phase 2 — classify (later)*
  - run object detection on the camera, fuse with the ToF, and publish *typed*
    detections (cable, sock, pet-waste, threshold, furniture …) with confidence.
    This is the NPU-relevant workload; keep it optional/pluggable.
- *react*
  - feed detections to navigation / [recovery-safety](../recovery-safety): slow,
    steer around, or stop-and-alert (e.g. never smear pet waste). Coordinate the
    interface rather than driving `cmd_vel` directly from here where a nav layer owns it.
- *(hardware track)* build a candidate front sensor (A/B/C above), run the test
  protocol, and publish the metrics table so the sensor choice is data-backed.
  Coordinate in [Discussions](https://github.com/makerspet/oomwoo/discussions?discussions_q=)
  before ordering parts so effort isn't duplicated.
- test it well
  - build worlds with *low obstacles the LiDAR can't see* (cable on the floor,
    sock, shoe, a 2 cm threshold) and verify they are detected and avoided
  - verify the robot still cleans normally when the near-field is clear (low false-positive rate)
- regression tests (headless, CI-friendly)
  - detection rate on a set of placed low obstacles (true-positive %)
  - false-positive rate on clear floor
  - "did not run over the flagged obstacle" success rate
- submit a PR (pull request) linking your ROS2 package(s) + sim sensor/world additions
  - instructions, documentation — install, run, configure, troubleshoot, test results
  - videos of low-obstacle detection and avoidance
  - announce your submission in [Project Discussions](https://github.com/makerspet/oomwoo/discussions?discussions_q=)
- iterate with review
- TBD, expect the RFC to evolve

## Acceptance criteria

Objective, measurable. Examples:
- *Below-LiDAR obstacles* (cable, sock, low threshold) are *detected* and
  published with distance/bearing, and the robot *avoids running them over*
- *Low false-positive rate* on clear floor — normal cleaning is not disrupted
- Phase 1 works *without* classification; Phase 2 classification is optional/pluggable
- *Regression tests* pass (detection %, false-positive %, avoidance success), runnable headless in CI
- Works in at least one world seeded with LiDAR-invisible obstacles
- *(hardware track)* a candidate is characterized against the Vacuum-Wars-style
  protocol *in light and darkness*, with the metrics table filled in — enough to
  compare it against the other approaches
- Documented and reliably reproducible by someone else
- TBD, expect criteria to evolve

The maintainer selects among compliant candidates using these criteria. Multiple
attempts are welcome and useful even if not selected — modules are swappable, and
a non-selected design is still a valid learning exercise and a fallback.

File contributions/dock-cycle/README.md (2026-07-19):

# Dock Cycle: undock, dock, recharge & station services (ROS2 package)

Everything around the charging/service *dock*. The robot must *undock* at the
start of a job, *return to the dock* (on completion or on low battery), *dock
precisely* to make charge contact, trigger *dock station services* (recharge,
and — where the dock supports them — auto-empty and mop-wash), and *find the dock
when it is lost* and relocalization has already failed. Because the physical robot
isn't built yet, this is a *Gazebo simulation*; it is later re-validated on
hardware in the [live-robot-bringup RFC](../live-robot-bringup).

> *Status — ready to start work.* No need to wait for OOMWOO hardware — develop it in the
> Gazebo sim ([urdf-gazebo-sim](../urdf-gazebo-sim)) or on the real
> [placeholder Proscenic M6 Pro](https://makerspet.com/blog/tutorial-connect-robot-vacuum-cleaner-to-ros-2-proscenic-m6-pro/).
> Say so in the [discussions](https://github.com/makerspet/oomwoo/discussions) so we can coordinate.

# Important References
- [nav-localize RFC](../nav-localize) — localization + Nav2; the find-the-dock fallback is invoked when its relocalization fails.
- [clean-and-map RFC](../clean-and-map) and [cleaning-jobs RFC](../cleaning-jobs) — trigger return-to-dock for recharge / auto-empty / mop-wash mid-job.
- [urdf-gazebo-sim RFC](../urdf-gazebo-sim) — robot URDF and Gazebo world(s) to model the dock in.
- [ROS2 software interfaces](../../docs/SOFTWARE_INTERFACES.md) — shared topic/action/service contract for simulation-first modules.
- Model a *generic basic charging dock* (charge contacts + a detectable marker). Exact dock geometry is TBD — the old teardown reference vacuum is no longer used.
- [OOMWOO ROS2 development](https://github.com/makerspet/oomwoo-install) — build OOMWOO ROS2 Docker image(s) with your packages.
- Nav2 docking (`opennav_docking`) is a good starting point for precise approach.
- [wennycooper/Auto-Docking-Design](https://github.com/wennycooper/Auto-Docking-Design) — reference IR homing design (dock IR emitter + baffled robot-side receivers).
- [Project discussions](https://github.com/makerspet/oomwoo/discussions?discussions_q=)
- [Discord server](https://discord.gg/3y2JKz5T25)

# Reference homing & dock-detection design (a good starting point)

Use `opennav_docking` for the docking *state machine*; this design is how you
*produce the dock pose* it needs, mirroring how consumer vacuums actually home.

- *In the dock:* an *IR homing beacon*. Start minimal — one *modulated* IR
  emitter (see [wennycooper/Auto-Docking-Design](https://github.com/wennycooper/Auto-Docking-Design)),
  enough for a centered final approach. A more robust dock (later) uses *coded
  left/right "buoy" beams + an omni "force-field" beam* (iRobot-style) so the
  robot can tell which side of the dock it is on from a distance.
- *On the robot, final approach:* *2× front IR receivers separated by a baffle* —
  the differential signal steers the robot to center on the beacon.
- *On the robot, search/acquisition:* *1× left + 1× right dock-detection IR
  receiver* (wider field of view) so the robot can detect the dock beacon and
  turn toward it *even when the dock location is unknown* (the find-the-dock case).

> *Shared hardware — coordinate with [floor-care](../floor-care).* These left/right
> side IR receivers do double duty: passive *dock detection* here, and active
> *wall following* in floor-care (same receiver, plus a side IR emitter, sensing
> the robot's own reflection). This matches the io-board GPIO (`Dock IR`,
> `Side proximity IR L/R`, `IR LED PWM`) and the merged `part-specs` (TSOP38238 +
> 940 nm). Because the beams are *modulated*, keep the dock beacon and the
> wall-illumination emitter *distinguishable* (different mode / time-multiplexed)
> so a wall reflection is never mistaken for the dock.

> *Sim note.* Gazebo has no IR sensor. Simulate the beacon receivers with a small
> *plugin / logical sensor* that computes line-of-sight + bearing (and a
> range-attenuated "strength") to the dock model, and any active proximity IR
> with a short-range narrow *ray* sensor. Add these inside your submission for now
> and propose folding the stable ones back into
> [urdf-gazebo-sim](../urdf-gazebo-sim) later — please don't rewrite that RFC.

# Request for Contribution - Instructions

- model the dock in Gazebo
  - add charge contacts and a *detectable marker* for the final approach (IR beacon, fiducial/AprilTag, or a reflective-intensity pattern the LiDAR can see)
  - model a *battery* (drain during cleaning, charge curve while docked) so low-battery behavior can be tested
  - model a *generic basic dock* (contacts + a detectable marker); exact geometry TBD
  - post in [Project Discussions](https://github.com/makerspet/oomwoo/discussions?discussions_q=) to let everyone know you're working on it, and post your progress
- undocking
  - safely back / drive out of the dock to a known start pose, then hand off to cleaning
- return-to-dock
  - navigate to the dock vicinity, triggered by *job complete* OR *low battery / full bin / mop needs washing* mid-job (coordinate with [cleaning-jobs](../cleaning-jobs))
- precise docking
  - final approach using the dock marker; align to the charge contacts; *confirm charging started*
- dock station services
  - once docked, trigger and wait for *recharge*, and — where the dock supports them — *auto-empty* and *mop-wash*; report completion so the job can resume
- find-the-dock-when-lost
  - fallback used when [nav-localize](../nav-localize) relocalization has *failed*: run a search pattern to reacquire the dock marker, dock, and re-establish pose from the known dock location
- test it well
  - start from *various poses and battery levels*; verify undock → clean → return → dock → service → resume
  - *kidnap* the robot so relocalization fails and verify find-the-dock recovers it
- regression tests (headless, CI-friendly)
  - docking success rate and final alignment error
  - find-the-dock success rate from random lost poses
  - low-battery return-then-resume completes without losing the job
- submit a PR (pull request) to `contributions/dock-cycle/<your-github-username>/`
  - link to ROS2 package(s) and the dock model / world additions
  - instructions, documentation - how to install, run, configure, troubleshoot, test results
  - videos of docking, find-the-dock, and low-battery return-and-resume
  - announce your submission in [Project Discussions](https://github.com/makerspet/oomwoo/discussions?discussions_q=)
- iterate with review
- TBD, expect the RFC to evolve

## Acceptance criteria

Objective, measurable. Examples:
- Robot *undocks* reliably to a known start pose
- Robot *returns and docks precisely*, making charge contact, from various poses (alignment within a stated tolerance)
- *Station services* (recharge; auto-empty / mop-wash where modeled) are triggered, completed, and reported
- *Low-battery mid-job* triggers return-to-dock and the job resumes after charging
- *Find-the-dock-when-lost* recovers a kidnapped robot after relocalization fails
- *Regression tests* pass (dock success, alignment error, find-the-dock success), runnable headless in CI
- Documented and reliably reproducible by someone else
- TBD, expect criteria to evolve

The maintainer selects among compliant candidates using these criteria. Multiple
attempts are welcome and useful even if not selected — modules are swappable, and
a non-selected design is still a valid learning exercise and a fallback.

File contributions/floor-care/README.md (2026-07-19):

# Floor-Surface Handling & Edge Cleaning (ROS2 package)

Clean *better* by adapting to the floor. This package adds *wall following* (to
clean tight against walls), *carpet-edge following*, recognizing *carpet vs
hardwood*, and *lifting / lowering the mop* accordingly (never wet a carpet).
Because the physical robot isn't built yet, this is a *Gazebo simulation* — you
model the surfaces and the surface sensor in Gazebo; it is later re-validated on
hardware in the [live-robot-bringup RFC](../live-robot-bringup).

> *Status — ready to start work.* No need to wait for OOMWOO hardware — develop it in the
> Gazebo sim ([urdf-gazebo-sim](../urdf-gazebo-sim)) or on the real
> [placeholder Proscenic M6 Pro](https://makerspet.com/blog/tutorial-connect-robot-vacuum-cleaner-to-ros-2-proscenic-m6-pro/).
> Say so in the [discussions](https://github.com/makerspet/oomwoo/discussions) so we can coordinate.

# Important References
- [clean-and-map RFC](../clean-and-map) — coverage cleaning that this refines at edges and surface transitions.
- [urdf-gazebo-sim RFC](../urdf-gazebo-sim) — robot URDF; this package likely needs a *surface sensor* and a *mop lift/lower actuator* modeled.
- [ROS2 software interfaces](../../docs/SOFTWARE_INTERFACES.md) — shared topic/action/service contract for simulation-first modules.
- [OOMWOO ROS2 development](https://github.com/makerspet/oomwoo-install) — build OOMWOO ROS2 Docker image(s) with your packages.
- [Project discussions](https://github.com/makerspet/oomwoo/discussions?discussions_q=)
- [Discord server](https://discord.gg/3y2JKz5T25)

> Note: this package may need new sim sensors/actuators (surface sensor, mop
> actuator). Add them inside your submission for now and propose folding the
> stable ones back into [urdf-gazebo-sim](../urdf-gazebo-sim) later — please don't
> rewrite that RFC.

# Request for Contribution - Instructions

- *wall following* — a *map-then-reactive* approach works well:
  - *(1) candidate walls:* from the map, find where walls are and plan an inward
    *offset contour* to follow (LiDAR-level, deliberative)
  - *(2) drive up to a wall* and *(3) confirm* the robot is actually beside it
    using *side IR wall sensors* (below)
  - *follow:* turn on a *side IR "wall illumination" emitter* and sense the
    wall's reflection on the *side IR receiver*; drive forward holding a constant
    reflected intensity (wall on the left: reflection *weaker* → steer slightly
    *toward* the wall; *stronger* → steer *away*). Add ROS2 enable/disable calls
    for the emitters.
  - integrate with [clean-and-map](../clean-and-map) coverage so edges *and* interior are both covered, without re-cleaning everything
  - post in [Project Discussions](https://github.com/makerspet/oomwoo/discussions?discussions_q=) to let everyone know you're working on it, and post your progress
  - > *Shared hardware — coordinate with [dock-cycle](../dock-cycle).* The side IR
    > receivers here are the same ones dock-cycle uses for dock detection (see the
    > io-board `Side proximity IR L/R` + `IR LED PWM`, and the merged `part-specs`
    > TSOP38238 + 940 nm). Caveat: reflected *intensity* also depends on wall
    > colour/reflectivity, so it is not an absolute range — the map+confirm step
    > (1–3) is what keeps intensity-following honest.
- *carpet-edge following*
  - detect carpet boundaries and follow the edge to clean along them
- *surface recognition (carpet vs hardwood)*
  - model a plausible sensor in sim (wheel current / IMU vibration / a dedicated downward sensor) and *publish the surface type*
- *mop lift / lower*
  - actuate the mop *up on carpet, down on hardwood*; model the actuator in Gazebo; *never wet a carpet*
  - coordinate with [cleaning-jobs](../cleaning-jobs) for mop-related job constraints
- test it well
  - build worlds with *mixed carpet + hardwood* regions and walls
  - verify edge coverage, correct surface classification, and correct mop state at every transition
- regression tests (headless, CI-friendly)
  - surface-classification accuracy
  - edge-coverage percentage (walls / carpet edges actually cleaned)
  - *zero carpet-wetting events* (mop never down on carpet)
- submit a PR (pull request) to `contributions/floor-care/<your-github-username>/`
  - link to ROS2 package(s) and any sim sensor/actuator + world additions
  - instructions, documentation - how to install, run, configure, troubleshoot, test results
  - videos of wall/edge following and mop lift/lower at surface transitions
  - announce your submission in [Project Discussions](https://github.com/makerspet/oomwoo/discussions?discussions_q=)
- iterate with review
- TBD, expect the RFC to evolve

## Acceptance criteria

Objective, measurable. Examples:
- *Wall / carpet-edge following* cleans tight along edges and integrates with coverage (high edge-coverage %)
- *Surface recognition* classifies carpet vs hardwood accurately
- *Mop lift/lower* tracks surface type correctly with *zero carpet-wetting events*
- *Regression tests* pass (classification accuracy, edge coverage, no carpet-wetting), runnable headless in CI
- Works in at least one *mixed carpet + hardwood* world
- Documented and reliably reproducible by someone else
- TBD, expect criteria to evolve

The maintainer selects among compliant candidates using these criteria. Multiple
attempts are welcome and useful even if not selected — modules are swappable, and
a non-selected design is still a valid learning exercise and a fallback.

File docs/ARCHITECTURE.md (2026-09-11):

# OOMWOO Architecture Brief

> *Status: DRAFT / skeleton.* This document defines the system so that modules
> can be built in parallel without colliding. Sections marked *TBD* are the
> gating decisions; until they are filled in, hardware modules that must fit
> together cannot be finalized. Treat the interface specs as the contract every
> module agrees to.

## 1. Purpose/Goal and scope

OOMWOO is an open-source, 3D-printed, ROS2-based home robot vacuum with 2D LiDAR
and Home Assistant support. It is designed to be *built from scratch by
the community*, module by module, clean well and to double as an affordable ROS2
development and learning platform.

*North star (not MVP):* OOMWOO is also the reference hardware for a broader
robot application platform. Architectural boundaries (especially the app layer in
§6) are drawn with that future in mind, but the MVP below deliberately excludes it.

## 2. Design principles

- *Open and swappable.* Every module has a defined interface. Any compliant
  implementation can replace another. No module depends on the internals of
  another, only on its published interface.
- *Simulation-first.* Software must run in Gazebo before it runs on hardware,
  so contributors with no robot can still build and test.
- *Affordable and printable.* Target off-the-shelf parts (a CM4/CM5-class compute
  module, common vacuum LiDARs, sourced Roborock/Dreame/Xiaomi motors and wear
  parts) and FDM-printable chassis parts.
- *Safety is reviewed, not crowd-trusted.* Battery, charging, and motor-driver
  modules pass a maintainer safety review before merge (see §8).
- *Reference-design backed.* A known-working vacuum (see the references in the
  [README](../README.md)) anchors the geometry and proves feasibility.

## 3. System overview

```
   LiDAR (UART, ~5 Hz) · MIPI camera(s) · IMU · serial audio
                    |
      +-------------v-------------------------------+
      |  CPU - CM4 / CM5 (or pin-compatible module) |
      |  ROS2 · SLAM (slam_toolbox) · Nav2 · behavior |
      |  educational variant: ESP32-S3 + micro-ROS  |
      |  (SLAM offboard on a dev PC over Wi-Fi)      |
      +-------------^----------------+---------------+
       serial (cmds/telemetry) +     |  custom serial protocol
       CPU-reset / health GPIO       |  (NOT micro-ROS)
      +-------------+----------------v---------------+
      |  MCU - STM32G473 (FreeRTOS, static alloc)    |
      |  motors · encoders · sensors · charging ctrl |
      |  SAFETY (no Linux/ROS2): bumper/cliff/wheel- |
      |  drop stop · current limit · CPU watchdog    |
      +-------------+--------------------+-----------+
                    |                    |
         +----------+----+      +--------+---------+
         | L/R drive     |      | suction fan,     |
         | wheels, brush |      | bumper, cliff,   |
         |               |      | IR, wheel-drop   |
         +---------------+      +------------------+

   Power: off-the-shelf 4S2P Li-ion pack (built-in BMS).
   The CPU module + MCU sit on one carrier I/O board.
```

> The CPU/MCU split keeps *all hard safety on the MCU*, independent of Linux/ROS2.
> Interfaces are largely decided (see §5); refine as the io-pcb spec settles.

## 4. Coordinate frames and conventions

- *TBD:* Define `base_link` origin and orientation (REP-103: x-forward,
  y-left, z-up). All mechanical mounting points and URDF frames reference this.
- *TBD:* Define the reference plane (floor contact), robot diameter, and height
  envelope. *These two numbers gate every hardware module.* Source these from the *sourced
  parts* + a 3D-scanned donor (see [source-3d-models](../contributions/source-3d-models));
  the current baseline is a ~349 mm round body ([oomwoo-one URDF](https://github.com/makerspet/oomwoo-one)).
- Units: millimeters, kilograms, SI. Right-handed frames. Angles in radians.

## 5. Hardware architecture

### 5.1 Chassis and reference frame
The chassis is the *integration backbone*. It publishes the mounting interface
every other hardware module targets. Reference geometry (dimensions, wheelbase,
motor specs, mass) comes from the *sourced parts* ([BOM](../BOM.md)) + 3D scans of
a donor vacuum (see [source-3d-models](../contributions/source-3d-models)); the
[oomwoo-one URDF](https://github.com/makerspet/oomwoo-one) carries the current
~349 mm round-body baseline.

- *TBD:* Overall diameter and height budget.
- *TBD:* Mounting grid / bolt pattern standard (e.g., M3 on a defined pitch).
- *TBD:* Mass budget per module and total target mass.

### 5.2 Mechanical interface standard (the contract)
Every hardware module's RFC must specify, against this standard:
- Mounting points (bolt pattern, location relative to `base_link`).
- Bounding envelope (max size the module may occupy).
- Mass budget.
- Mating tolerances and print orientation.
- *TBD:* Define the standard connector/fastener set (screw sizes, heat-set
  inserts, etc.) so parts from different authors actually mate.

### 5.3 Electrical interface standard (the contract)
- *Battery:* off-the-shelf pack with a *built-in BMS* — *4S2P Li-ion*, ~14.4 V
  nominal, ~5200 mAh / ~75 Wh (OEM BRR-2P4S-5200 class), charged 16.8 V CC/CV with
  NTC temperature sense. Chemistry is now decided; see the [BOM](../BOM.md).
- *TBD:* Power rails distributed to modules (VBAT, 5V, 3.3V) and connector types/pinouts.
- *CPU ↔ MCU:* a *custom high-speed serial protocol* (not micro-ROS) carries
  commands/telemetry, plus discrete GPIOs (CPU power on/off, and a CPU-reset line
  the MCU asserts on missed health packets). The *MCU owns motors and sensors*; the
  CPU never drives them directly.
- *Sensors:* bumper/cliff/wheel-drop and analog IR are *MCU-side* (digital in / ADC);
  the *LiDAR (UART, ~5 Hz)*, MIPI camera(s), IMU, and serial audio attach to the *CPU*.

### 5.4 Compute (CPU) and real-time controller (MCU)

OOMWOO splits compute across two processors — mirroring how consumer vacuums are
built, and, crucially, so that *safety never depends on Linux/ROS2*.

*CPU (compute module).* The I/O board is a *carrier* that accepts a *Raspberry Pi
Compute Module 4 or 5* and — because the CM4 pinout is a de-facto standard — the
many *pin-compatible alternative modules* (Radxa CM3/CM4, Pine64 SOQuartz, LuckFox
Core3566, …), several with an *NPU* for future on-device vision. The CPU runs
*ROS2, SLAM (slam_toolbox), Nav2, LiDAR processing, and high-level behavior*. CM
modules are low-profile (helps the height budget) and swappable (hackable, cheaper,
NPU options).
- *Minimum target: a 4 GB CM4/CM5 (or Pi 4).* Realistic prior art runs
  slam_toolbox + Nav2 onboard a 4 GB Pi 4. Getting the floor to *2 GB* is a goal
  (ROS2 composable nodes; selectively rewriting heavy Python nodes in Rust/C++) —
  *no guarantee*, to be settled by the compute-benchmark. No 8–16 GB module needed.
- *Cooling:* no dedicated CPU fan — the suction fan's airflow cools the compute
  board, as in consumer vacuums.
- The earlier bespoke *RK3562* reference schematic is *dropped* in favour of the
  CM4/CM5 carrier.

*MCU (real-time / safety controller).* A dedicated *STM32G473VCT6* microcontroller
(Cortex-M4F, LQFP100, multiple ADCs and timer resources), selected by the current
I/O-board design, owns *motors, encoders, all sensors, battery-charging control,
and safety*. Its
role is *fixed*: functionality does not migrate onto the CPU, and CPU work does not
migrate onto the MCU.
- Firmware uses a layered *FreeRTOS* design (static allocation, watchdog, bounded
  reaction times, CE-oriented) speaking a *custom serial protocol — not micro-ROS*
  (the tried-and-true consumer-vacuum approach; cf. the reverse-engineered
  [3irobotix protocol](https://github.com/codetiger/VacuumRobot)).
- *Hard safety lives here, independent of Linux/ROS2:* the MCU stops all motors on
  a *bumper hit, cliff detection, or wheel-drop*, current-limits a *stuck brush*,
  and *watchdogs the CPU* — if the CPU's health packets stop, it stops the motors
  and can *reset the CPU*.
- Tentative ~60-signal pin budget: see the [io-pcb RFC](../contributions/io-pcb)
  appendix (why the MCU needs a high-GPIO part).

*CPU ↔ MCU link.* A *high-speed serial* channel carries commands/telemetry both
ways, plus discrete GPIOs — notably the *CPU-reset* line the MCU asserts on missed
health packets, and CPU power on/off. The draft protocol, ROS2 bridge mapping,
and bringup checklist live in the [io-board-interface RFC](../contributions/io-board-interface).
Any LiDAR supported by `kaiaai/LDS` / `lds2d` is interface-compatible.

### 5.5 Two build profiles

The same carrier I/O board + MCU supports two swappable compute configurations:

| | *Consumer / regular* | *Educational / lower-cost* |
|---|---|---|
| CPU-slot module | CM4 / CM5 (or pin-compatible alt) | *ESP32-S3* board in the CM4 form factor |
| Where ROS2 / SLAM runs | *onboard* (ROS2 + slam_toolbox + Nav2) | *offboard* on a local dev PC; ESP32-S3 runs *micro-ROS* |
| Link | self-contained robot | robot ↔ dev PC over *Wi-Fi* |
| Trade-off | plug-and-play for non-experts | cheaper, but Wi-Fi congestion / dead-zones — a learning platform, not a polished consumer product |

Onboard SLAM is the default for the consumer version *so non-experts can build and
use it* without setting up a separate ROS2 dev machine. The ESP32-S3 can only be
the *CPU-slot* option — it lacks the ~60 GPIO the MCU role needs, so it never
replaces the STM32.

## 6. Software architecture

### 6.1 ROS2 graph (MVP)
- Core nodes (MVP): LiDAR driver, base controller (diff-drive), odometry,
  teleop, SLAM (manual mapping), TF/URDF publisher.
- *Interface contract:* each software module's RFC declares the ROS2 topics,
  services, message types, and parameters it publishes/consumes. Modules depend
  on these interfaces, not on each other's code. See
  [SOFTWARE_INTERFACES.md](SOFTWARE_INTERFACES.md) for the current draft ROS2
  graph contract.

### 6.2 Simulation
- Gazebo + URDF, with a set of residential-layout worlds for navigation and
  coverage testing. Sim parity is a first-class requirement, not an afterthought.

### 6.3 Application layer (Phase 2 — north star, NOT in MVP)
A ROS2-agnostic layer that runs third-party apps locally in isolated *Podman*
containers, so app developers need no ROS2 expertise. Documented here only to
keep its boundary clean; *explicitly out of scope for the Aug 31 MVP.*

## 7. MVP definition (target: 2026-08-31)

*In scope:* ROS2 on a CM4/CM5-class compute module · LiDAR · manual SLAM/mapping · teleop drive ·
3D-printed chassis · Gazebo sim with URDF · evaluation + demo video. No dock,
no autonomous exploration, no Home Assistant, no app layer.

*Explicit non-goals for MVP:* autonomous coverage, docking, auto-empty, mopping,
Home Assistant, the app platform, accessories. These are later phases.

*Critical-path ownership:* the maintainer (+ small core) own the chassis,
interface specs, and integration so the MVP does not depend on volunteer delivery
timing. Community modules accelerate and improve the MVP; they do not block it.

## 8. Safety review gate

Battery, charging, motor-driver, and mains-adjacent modules require maintainer
safety review before merge. RFCs for these modules must include a hazard note
(over-current, thermal, short, mechanical pinch).

The battery risk is *reduced* by using an *off-the-shelf 4S2P Li-ion pack with a
built-in BMS* (over-charge / over-discharge / short protection); the review then
focuses on the *16.8 V CC/CV charging path + NTC temperature sense*. *Hard safety
lives on the MCU, never on Linux/ROS2* — it independently stops motors on
bumper/cliff/wheel-drop, current-limits a stuck brush, and watchdog-resets the CPU.

## 9. Roadmap (phases after MVP)

1. Rechargeable battery + basic dock + autonomous floor mapping.
2. Home Assistant integration.
3. Application layer (Podman app runtime) + first delightful apps.
4. Accessories and novel apps; integrations (e.g., LeRobot arm).

## 10. Open questions

- *Resolved:* the MCU runs a *custom serial protocol (not micro-ROS)*; the CPU runs
  *onboard ROS2/SLAM/Nav2*. micro-ROS is used only in the *educational* ESP32-S3
  profile (SLAM offboard on a dev PC). See §5.4–5.5.
- *Resolved:* battery is an off-the-shelf *4S2P Li-ion pack with a built-in BMS*,
  charged 16.8 V CC/CV. See §5.3, §8.
- Can OOMWOO's onboard ROS2 stack fit in *2 GB* (composable nodes, selective Rust)
  rather than 4 GB? To be answered by the compute-benchmark.
- *Resolved:* the reference I/O board uses *STM32G473VCT6*, superseding the earlier
  STM32G070 candidate. Pin-compatible alternatives remain a separate board-design
  decision.
- One hardware-agnostic HAL covering reference vacuum + DIY builds (community idea)?
- Module selection process: who decides which competing implementation wins, and
  on what criteria? (See each module's acceptance criteria.)

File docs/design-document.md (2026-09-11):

# OOMWOO Design Document

> *Working design doc.* This accumulates research-backed design decisions before
> they're split into per-module [RFCs](../contributions) and the [RFC backlog](RFC_BACKLOG.md), and/or migrated into
> the [README](../README.md). A condensed version of §1 already lives in the
> README's [Design research](../README.md#design-research) section. Expect this to
> grow as remaining components are researched.

---

## 1. Design research — what makes vacuum users happy

We reviewed the 2025–2026 consumer robot vacuum landscape (global + China-sourceable
brands, budget → flagship) across RTINGS, VacuumWars, Reddit r/robotvacuums, and
reviewer blogs, then adversarially fact-checked the key claims. The point: copy the
solutions that correlate with happy users, skip the ones that need commercial scale.
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

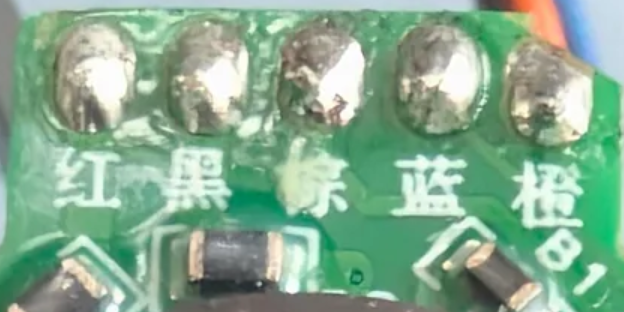
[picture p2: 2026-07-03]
contributions/part-specs/Scowt/WM_V2_closeup.png

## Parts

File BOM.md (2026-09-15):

# Bill of Materials (work in progress)

Blog post - how I'm making this BOM [How-to: Source BOM for OOMWOO Open-Source Vacuum Robot](https://makerspet.com/blog/how-to-source-bom-for-oomwoo-open-source-vacuum-robot/)

Rationale in [docs/design-document.md](docs/design-document.md).

---

## Budget target

~$200 in sourced parts + a Raspberry Pi 5 (4 GB), aiming at the capability of a
mid-range ($500–600) commercial vacuum with mopping, possibly premium obstacle detection (ToF +
color camera + an NPU accelerator).

## Robot BoM (work in progress)

Retail / low-qty prices, INCLUDES shipping, excludes tax. Read [how I calculate BoM costs](#how-i-calculate-costs).

| Item | Qty | ~USD | Notes | Source |
|---|---|---|---|---|
| Drive wheel assembly pair | 1 | $24-$33 | Motor + encoder + suspension + tire + cables + wheel-drop sensors | Roborock S4 Max, S45 Max, S5 Max, S50 Max, S55 Max, S6 MaxV, S6 Pure, S65 Pure, S65 MaxV, S7, S7 Pro, S7 MaxV, S7 Max Ultra, S70, S75, E4, E45, E5, E50, E55, G10, T7, T7S, Q5, Q7, Q7 Max, and Q Revo [AliExpress](https://www.aliexpress.us/w/wholesale-roborock-s5-maxv-wheels.html) / [Amazon](https://www.amazon.com/s?k=roborock+s5+maxv+wheels) / [eBay](https://www.ebay.com/sch/i.html?_nkw=roborock+s5+maxv+wheels) |
| | | $24-$33 | Motor + encoder + suspension + tire + cables + wheel-drop sensors | Roborock S5, S50, S51, S52, S55, S502, and the budget C10, E20, E25 and E35 [AliExpress](https://www.aliexpress.us/w/wholesale-roborock-s5-wheels.html) / [Amazon](https://www.amazon.com/s?k=roborock+s5+wheels) / [eBay](https://www.ebay.com/sch/i.html?_nkw=roborock+s5+wheels) |
| Caster wheel | 1 | $2.50-$5 | Push-in | iRobot Roomba I3/4/6/8, J7/Plus J7 E5/6 500 600 700 800 900 [AliExpress](https://www.aliexpress.us/w/wholesale-roomba-caster.html) / [Amazon](https://www.amazon.com/s?k=roomba+caster) / [eBay](https://www.ebay.com/sch/i.html?_nkw=roomba+caster) |
| Suction fan | 1 | $10–23 | 6 kPa option | Dreame MSD-C-3, Nidec 20N709U020; fits Dreame L10s Prime/Pro, *L10s Ultra Gen 1* (5.3 kPa — Gen 2 is 10 kPa!), D10s Plus, X10+ (6 kPa); X20+ verify (~7 kPa?) [AliExpress](https://www.aliexpress.us/w/wholesale-Dreame-L10s-fan.html) / [Amazon](https://www.amazon.com/s?k=Dreame+L10s+fan) / [eBay](https://www.ebay.com/sch/i.html?_nkw=Dreame+L10s+fan) |
| | | $17–28 | 5.1-6 kPa option | Nidec 22N704W150, 20N704S980, 20N704R980L; fits Roborock S8 Pro Ultra, S7 MaxV (5.1 kPa), S8/S8+/S8 Plus (6 kPa); G20 (Q7 Max/Max+ excluded — they're 4.2 kPa, not 5-6) [AliExpress](https://www.aliexpress.us/w/wholesale-roborock-s8-pro-fan.html) / [Amazon](https://www.amazon.com/s?k=roborock+s8+pro+fan) / [eBay](https://www.ebay.com/sch/i.html?_nkw=roborock+s8+pro+fan) |
| | | $12–24 | 10 kPa option | Roborock BL24131616; Nidec 22N704V160; fits Roborock S8 MaxV Ultra (10 kPa); G20S [AliExpress](https://www.aliexpress.us/w/wholesale-roborock-g20s-fan.html) / [Amazon](https://www.amazon.com/s?k=roborock+g20s+fan) / [eBay](https://www.ebay.com/sch/i.html?_nkw=roborock+g20s+fan) |
| | | $34–45 | 36 kPa option | Roborock Saros 20 [AliExpress](https://www.aliexpress.us/w/wholesale-Roborock-Saros-20-fan.html) / [Amazon](https://www.amazon.com/s?k=Roborock+Saros+20+fan) / [eBay](https://www.ebay.com/sch/i.html?_nkw=Roborock+Saros+20+fan) |
| | | $12–25 | 2-2.5 kPa option | Nidec 20N704P200, 20N704R500, 20N704R310, 20N704P160; Xiaomi Roborock S50 S51 S55 S60 S61 S65 S5 MAX S6 E25 E35, S5, S6 Pure [AliExpress](https://www.aliexpress.us/w/wholesale-roborock-s5-fan.html) / [Amazon](https://www.amazon.com/s?k=roborock+s5+fan) / [eBay](https://www.ebay.com/sch/i.html?_nkw=roborock+s5+fan) |
| Main brush | 1 | $5-$8 | Single roller, rubber and bristles | Fits Roborock S4, S4 Max, S5, S5 Max, S50/S55, S6, S6 Pure/MaxV, S60/S65, E2,E3,E4,E5, E20,E25,E35, C10, Xiaomi Mijia [AliExpress](https://www.aliexpress.us/w/wholesale-roborock-s5-brush.html) / [Amazon](https://www.amazon.com/s?k=roborock+s5+brush) / [eBay](https://www.ebay.com/sch/i.html?_nkw=roborock+s5+brush) |
| | | $8-$12 | Anti-tangle dual roller, rubber only | Fits Roborock S8 MaxV Ultra, G20S V20, P10S Pro/Pro Plus [AliExpress](https://www.aliexpress.us/w/wholesale-roborock-G20S-v20-brush.html) / [Amazon](https://www.amazon.com/s?k=roborock+G20S+v20+brush) / [eBay](https://www.ebay.com/sch/i.html?_nkw=roborock+G20S+v20+brush) |
| | | $3-$5 | Single roller, rubber only | Fits Roborock S7, S70, S7+/MaxV/MaxV Plus/MaxV Ultra/Pro, Q Revo/Pro/Plus, Q5, Q5+, Q7, Q7 Max, QV 35S, T7S, T7S Plus [AliExpress](https://www.aliexpress.us/w/wholesale-Roborock-S7-main-brush.html) / [Amazon](https://www.amazon.com/s?k=Roborock+S7+main+brush) / [eBay](https://www.ebay.com/sch/i.html?_nkw=Roborock+S7+main+brush) |
| | | $5-$10 | Anti-tangle split single roller, rubber and bristles | Fits Roborock Saros 10/10R, Saros 20, Saros 20 Sonic, S10 MaxV Ultra, S9 MaxV/MaxV Ultra, QRevo 5AE/Edge/Edge C/Edge S5A/5V1/X/Edge T/Curv/S5V/Curv S5X/P20 Pro [AliExpress](https://www.aliexpress.us/w/wholesale-Roborock-saros-10-main-brush.html) / [Amazon](https://www.amazon.com/s?k=Roborock+saros+10+main+brush) / [eBay](https://www.ebay.com/sch/i.html?_nkw=Roborock+saros+10+main+brush) |
| | | $20-$30 | Anti-tangle hair-cutting dual roller, rubber and bristles | Fits Dreame L40s Ultra, L40 Ultra, X40, X40 Ultra, X30 Ultra, L30 Ultra, L20 Ultra, L10s Ultra/Ultra Gen 2/Pro Ultra, S10 Pro, S20, S20 Pro/Pro Plus, X10, X10+, X20 Pro, D9 Max Gen2; Mova E30 Ultra, S10 Plus, P10 Pro Ultra; Xiaomi S10+, X20 Pro, X10+, Mijia M30S/M40 [AliExpress](https://www.aliexpress.us/w/wholesale-dreame-tricut-brush.html) / [Amazon](https://www.amazon.com/s?k=dreame+tricut+brush) / [eBay](https://www.ebay.com/sch/i.html?_nkw=dreame+tricut+brush) |
| | | $7-$10 | Anti-tangle tapered dual roller, rubber and bristles | Fits Dreame X60 Max, X50 Ultra/Master/Pro Ultra, L40S Pro Ultra/Ultra; MOVA V50 Ultra [AliExpress](https://www.aliexpress.us/w/wholesale-dreame-x50-ultra-main-brush.html) / [Amazon](https://www.amazon.com/s?k=dreame+x50+ultra+main+brush) / [eBay](https://www.ebay.com/sch/i.html?_nkw=dreame+x50+ultra+main+brush) |
| | | $7-$10 | Anti-tangle dual roller, rubber only + rubber and bristles options| Fits Roborock Roborock S8, S8+/Pro Ultra, Q5 Pro/Pro+, Q8 Max/Max+, G20 [AliExpress](https://www.aliexpress.us/w/wholesale-Roborock-Q8-Max-main-brush.html) / [Amazon](https://www.amazon.com/s?k=Roborock+Q8+Max+main+brush) / [eBay](https://www.ebay.com/sch/i.html?_nkw=Roborock+Q8+Max+main+brush) |
| Battery pack + BMS | 1 | $16–30 | OEM BRR-2P4S-5200, 4S2P-MMBK P2150-4S2P-XWDLS; 14.4V Li-ion, ~5200 mAh / 75 Wh in-pack BMS. | Fits Xiaomi Mijia 1/1S/1C/1T/G1, Roborock S4/S5/S5 Max/S6/S6 Pure/MaxV/S7/S7 MaxV, Q5/Q7 Max, T4/T6/T7/T60/T65, Xiaowa E20/E25/E35, C10 [AliExpress](https://www.aliexpress.us/w/wholesale-BRR-2P4S-5200-battery.html) / [Amazon](https://www.amazon.com/s?k=BRR+2P4S+5200+battery) / [eBay](https://www.ebay.com/sch/i.html?_nkw=BRR+2P4S+5200+battery) 4-pin connector B+, B−, NTC, sense (TODO verify). Safety review narrows to: 16.8 V CC/CV charge + NTC temp sense. |
| 2D LiDAR  | 1 | $16-26 | PCB mark X-WPFTB-V2.6.2, possibly Camsense | Fits Dreame L10s/Pro/Ultra/Prime, L10 Ultra, L20 Pro/Ultra, L30 Ultra, W10s/Pro, W20,  Xiaomi X10+, X30s Pro, X30 Plus/Pro/Ultra, X20 Pro, X40/Pro/Pro Plus, X10/Plus, X20/Plus, S10/Pro/Plus/Ultra, S20+ |
| | | $16-27 | PCB mark X-Wireless board-V1.13.3, possibly Camsense | Fits Dreame W10, F9, D9, D9 Pro/Plus/max, L10 Pro, Z10 Pro [AliExpress](https://www.aliexpress.us/w/wholesale-Dreame-L10s-lds.html) / [Amazon](https://www.amazon.com/s?k=Dreame+L10s+lds) / [eBay](https://www.ebay.com/sch/i.html?_nkw=Dreame+L10s+lds) |
| | | $14-32 | Xiaomi LDS02RR, LDS01RR | Fits Roborock S5/S50/51/55/S6/S7, S502-00/01/02/03, S550-00, S5 Max, S6 MaxV/Pure, S45 Max, S7 Max, Xiaomi Mi 1s [AliExpress](https://www.aliexpress.us/w/wholesale-roborock-s5-lds.html) / [Amazon](https://www.amazon.com/s?k=roborock+s5+lds) / [eBay](https://www.ebay.com/sch/i.html?_nkw=roborock+s5+lds) |
| | | $13-25 | 3irobotix Delta-2A/B/G | Fits Xiaomi Mijia Mop P Pro, Mop 2S, 3C S10, S12 T12 [AliExpress](https://www.aliexpress.us/w/wholesale-xiaomi-mop-lds.html) / [Amazon](https://www.amazon.com/s?k=xiaomi+mop+lds) / [eBay](https://www.ebay.com/sch/i.html?_nkw=xiaomi+mop+lds) |
| | | $13-23 | Possibly LDROBOT LD14P | Fits Dreame X30 X40 Series, Xiaomi Mijia X20 Plus, Mop2 [AliExpress](https://www.aliexpress.us/w/wholesale-dreame-x30-lds.html) / [Amazon](https://www.amazon.com/s?k=dreame+x30+lds) / [eBay](https://www.ebay.com/sch/i.html?_nkw=dreame+x30+lds) |
| Compute Module | 1 | $62.50*  | Raspberry Pi CM4 ≥2 GB | CM4102000 [PiShop](https://www.pishop.us/product/raspberry-pi-compute-module-4-wireless-2gb-lite-cm4102000/) [Newark](https://www.digikey.com/en/products/detail/raspberry-pi/SC0667/13530921) [DigiKey](https://www.newark.com/raspberry-pi/cm4102000/rpi-compute-module-4-lite-2gb/dp/86AH2093) CM4102008 CM4102016 CM4102032 |
| | | $72.50* | Raspberry Pi CM5 ≥2 GB | CM5102000 [PiShop](https://www.pishop.us/product/raspberry-pi-compute-module-5-wireless-2gb-ram-lite-cm5102000/) [Newark](https://www.newark.com/raspberry-pi/cm5102000/som-rpi-compute-mod-5-lite-2gb/dp/20AM3775) [DigiKey](https://www.digikey.com/en/products/detail/raspberry-pi/SC1586/25805584) CM5102016 CM5102032 CM5104064 |
| Cliff sensors | 4 | $1.50-2.50 ea | 4x cliff + 2x bumper w/cables bundle | iRobot Roomba 500 600 700 800 528 552 564 595 560 570 610 615 620 625 630 650 [AliExpress](https://www.aliexpress.us/w/wholesale-irobot-roomba-500-cliff.html) / [Amazon](https://www.amazon.com/s?k=irobot+roomba+500+cliff) / [eBay](https://www.ebay.com/sch/i.html?_nkw=irobot+roomba+500+cliff) |
| Bumper switches | 2 | $0 | Included in cliff sensors bundle | |
| Main brush motor, gearbox | 1 | $7-11 | Requires brush socket adapter | Fits Roborock S5, S50, S51, S52, 55 502-00/01/02/03**S552-00, S6; Xiaowa C10, E20, E25, E35 [AliExpress](https://www.aliexpress.us/w/wholesale-roborock-s5-main-brush-motor.html) / [Amazon](https://www.amazon.com/s?k=roborock+s5+main+brush+motor) / [eBay](https://www.ebay.com/sch/i.html?_nkw=roborock+s5+main+brush+motor) |
| Side brush | 1 | $2-8 | 5-arm | Used in Roborock S5, S50, S51, S55, S6, S60, S6 Pure; fits many other Roborock models [AliExpress](https://www.aliexpress.us/w/wholesale-roborock-s5-side-brush.html) / [Amazon](https://www.amazon.com/s?k=roborock+s5+side+brush) / [eBay](https://www.ebay.com/sch/i.html?_nkw=roborock+s5+side+brush) |
| | | $3-9 | 3-arm | Used in Roborock S8; fits many other Roborock models [AliExpress](https://www.aliexpress.us/w/wholesale-roborock-s8-side-brush.html) / [Amazon](https://www.amazon.com/s?k=roborock+s8+side+brush) / [eBay](https://www.ebay.com/sch/i.html?_nkw=roborock+s8+side+brush) |
| | | $3-7 | 2-arm curved | Used in Roborock Saros; possibly fits many other Roborock models [AliExpress](https://www.aliexpress.us/w/wholesale-roborock-saros-side-brush.html) / [Amazon](https://www.amazon.com/s?k=roborock+saros+side+brush) / [eBay](https://www.ebay.com/sch/i.html?_nkw=roborock+saros+side+brush) |
| Side brush motor | 1 | $7-10 | Fixed | Fits Roborock S5, S50, S51, S52, S55, S502-00/01/02/03** S552-00, S5 Max, S6, S6 Pure, S6 MaxV, S60, S61, S65, S7, S7 MaxV, S7 Plus, S70, S75, Xiaowa/Xiaomi C10 E20 E25 E35 [AliExpress](https://www.aliexpress.us/w/wholesale-roborock-s5-side-brush-motor.html) / [Amazon](https://www.amazon.com/s?k=roborock+s5+side+brush+motor) / [eBay](https://www.ebay.com/sch/i.html?_nkw=roborock+s5+side+brush+motor) |
| | | $18-35 | Extendable | FlexiArm fits Roborock Qrevo Master, Qrevo Edge, Qrevo Slim, Qrevo Pro, Qrevo S Pro, S8 MaxV Ultra, S8 Max Ultra, Q55 Pro, G20, G20S, V20 [AliExpress](https://www.aliexpress.us/w/wholesale-roborock-qrevo-side-brush-motor.html) / [Amazon](https://www.amazon.com/s?k=roborock+qrevo+side+brush+motor) / [eBay](https://www.ebay.com/sch/i.html?_nkw=roborock+qrevo+side+brush+motor) |
| Wall sensor | 2 | $3 | Custom PCB | TSOP38238 IR receiver for dock detection; VL6180 distance sensors; VL53L0CX, VL53L4CD, TMF8806 or similar as backup; Sharp-like analog distance sensor if dust causes problems |
| Dock homing sensor | 1 | $3 | Custom PCB | 2x TSOP38238 IR receivers |
| Carpet sensor | 1 | $6-12 | Ultrasonic 300kHz | Low availability retail [AliExpress](https://www.aliexpress.us/w/wholesale-roborock-carpet-sensor.html) / [Amazon](https://www.amazon.com/s?k=roborock+carpet+sensor) / [eBay](https://www.ebay.com/sch/i.html?_nkw=roborock+carpet+sensor); purchase factory direct instead |
| Charging contacts | 1 pair | $3-5 | Nickel-plated steel strip | ≥10mm wide, ≥0.1mm thick, ~5cm long [AliExpress](https://www.aliexpress.us/w/wholesale-nickel-strip.html) / [Amazon](https://www.amazon.com/s?k=nickel+strip) / [eBay](https://www.ebay.com/sch/i.html?_nkw=nickel+strip) |
| Mop motor assembly | 1 pair | $20 | Spin, lift, one swing | Rare/expensive retail, get 2x $5 RS385 12V motors, 2x $2.50 MG90S, wires, 3D print rest or order factory direct for kit; [AliExpress](https://www.aliexpress.us/w/wholesale-roborock-mop-motor.html) / [Amazon](https://www.amazon.com/s?k=roborock+mop+motor) / [eBay](https://www.ebay.com/sch/i.html?_nkw=roborock+mop+motor) |
| Mop disk | 1 pair | n/a | Left, right | 3D print; refer to [AliExpress](https://www.aliexpress.us/w/wholesale-roborock-mop-holder.html) / [Amazon](https://www.amazon.com/s?k=roborock+mop+holder) / [eBay](https://www.ebay.com/sch/i.html?_nkw=roborock+mop+holder) |
| Obstacle avoidance vis camera | 2 | $6-7 | OV5647 5M MIPI 16-pin cable, 130 deg, no IR-cut filter | Wide FoV depth-from-stereo for advanced obstacle avoidance, search "night vision" [AliExpress](https://www.aliexpress.us/w/wholesale-ov5647-night-vision.html) / [Amazon](https://www.amazon.com/s?k=ov5647+night+vision) / [eBay](https://www.ebay.com/sch/i.html?_nkw=ov5647+night+vision) |
| ~~Obstacle detection range camera~~ | ~~1~~ | ~~$8–15~~ | ~~VL53L7CX or VL53L7CH, 8x8 obstacle detection (90° FoV)~~ | ~~Expensive if purchased on AliExpress. Sensor IC costs around $5.50 at DigiKey/Mouser/STMicro. [AliExpress](https://www.aliexpress.us/w/wholesale-VL53L7CX.html) / [Amazon](https://www.amazon.com/s?k=VL53L7CX) / [eBay](https://www.ebay.com/sch/i.html?_nkw=VL53L7CX)~~ |
| Water pump | 1 | $3.50 | Peristaltic 5-12V DC ≥50ml/min, tube 2mm ID 4mm OD | CONJOIN CJWP12 or similar [AliExpress](https://www.aliexpress.us/w/wholesale-CJWP12.html) / [Amazon](https://www.amazon.com/s?k=CJWP12) / [eBay](https://www.ebay.com/sch/i.html?_nkw=CJWP12) |
| LiDAR tower bumper sensor | 4 | $0.70 | Micro switches | SPDT or similar [AliExpress](https://www.aliexpress.us/w/wholesale-spdt-switches.html) / [Amazon](https://www.amazon.com/s?k=spdt+switches) / [eBay](https://www.ebay.com/sch/i.html?_nkw=spdt+switches) |
| HEPA filter | 1 | $2-3 | ~20 kPa ~110 x 48 x 22mm | Fits Dreame X50 Pro, X50 Ultra, X50 Master, L40s Pro Ultra, L50 Pro Ultra, S40 Enhanced, X40 Pro Enhanced, RLX93CE, X50 Master, Mova V50 Ultra [AliExpress](https://www.aliexpress.us/w/wholesale-dreame-x50-pro-filter.html) / [Amazon](https://www.amazon.com/s?k=dreame+x50+pro+filter) / [eBay](https://www.ebay.com/sch/i.html?_nkw=dreame+x50+pro+filter) |
| | 1 | $2-3 | ~36 kPa ~113 x 59 x 12 mm | Fits Roborock Saros 10R, Saros Z70, Saros 20 Sonic, Saros 20, Qrevo Curv 2 Pro, Qrevo CurvX, Qrevo EdgeT, S10 MaxV Slim, S10 MaxV Ultra, S9 MaxV Slim, G20S Ultra, P20 Ultra, P20 Plus, P20 Ultra Plus, G30 Ultra, G30S Pro [AliExpress](https://www.aliexpress.us/w/wholesale-roborock-saros-20-filter.html) / [Amazon](https://www.amazon.com/s?k=roborock+saros+20+filter) / [eBay](https://www.ebay.com/sch/i.html?_nkw=roborock+saros+20+filter) |
| | 1 | $2-3 | ~35 kPa ~102/85 x 49 x 26mm | Fits Dreame X60 Ultra, X60 Max Ultra, X60 Max Ultra Complete [AliExpress](https://www.aliexpress.us/w/wholesale-dreame-x60-ultra-filter.html) / [Amazon](https://www.amazon.com/s?k=dreame+x60+ultra+filter) / [eBay](https://www.ebay.com/sch/i.html?_nkw=dreame+x60+ultra+filter) |
| Speaker | — | 3–8 | | |
| Custom I/O PCB | 1 | ~40 | STM32 + motor drivers + sensor front-ends | |
| Wiring, connectors, fasteners, magnets, gaskets, filter, tubing | — | 12–25 | | |
| Printed parts (filament) | — | 5–15 | you print these yourself | |
| Tires | 2 | $2-3 | 57mm ID, 68mm OD, 14mm width | Only needed if building drive wheels from scratch. Fit IRobot Roomba Vacuum 500, 600, 700, 800, 900, E5, E6, i7 Series
[AliExpress](https://www.aliexpress.us/w/wholesale-roomba-tire-skin.html) / [Amazon](https://www.amazon.com/s?k=roomba+tire+skin) / [eBay](https://www.ebay.com/sch/i.html?_nkw=roomba+tire+skin)
|
| *Robot subtotal (sourced parts)* | | *~$130–270* | excludes SBC | |

## Dock

| Item | Qty | ~USD | Notes | Source |
|---|---|---|---|---|
| Water pumps | 3 | $5-8 | Diaphragm 24 V self-priming clean-feed + dirty-evacuate + tank refill | [AliExpress](https://www.aliexpress.us/w/wholesale-water-pump-24v.html) / [Amazon](https://www.amazon.com/s?k=water+pump+24v) / [eBay](https://www.ebay.com/sch/i.html?_nkw=water+pump+24v) |
| Auto-empty suction fan | | $10-20 | 21.6–25.2V 65mm 350W | Budget stick-vac class like Dreame P10's BLDC M10-E-4 25.2V 310W motor; no particular model abundant, but multiple same-size/same-power models; BLDC motor Nidec 13F704P640, non-Nidec 64XC216-085D, MBD65. Weak-ish compared to consumer auto-empty docks, but can work with an external power adapter to keep mains wiring out of dock, away from mop water. [AliExpress](https://www.aliexpress.us/w/wholesale-fan-motor-350w.html) / [Amazon](https://www.amazon.com/s?k=fan+motor+350w) / [eBay](https://www.ebay.com/sch/i.html?_nkw=fan+motor+350w) |
| | | TBD | 110VAC 1200W | Match consumer auto-empty dock; requires mains inside dock enclosure. |
| Power supply | 1 | $33 | 400W external | IP67 proof 24V "LED driver" [Amazon](https://www.amazon.com/s?k=24v+led+strip+power+supply+400w) / [eBay](https://www.ebay.com/sch/i.html?_nkw=24v+led+strip+power+supply+400w) |
| | | TBD | Internal |  |
| Dock board | 1 | ~30 | DC inlet + fuse + TVS, ESP32 MCU/WiFi, high-side FET/relay for blower, IR homing beacon, push button(s), robot presence detect, charge contacts FET, pump/fan drivers |  |
| Water level, canisters present sensors | 4 | $0.30 | Hall sensors KY-003, 2x (clean + dirty water) canister present + 2x (clean-low, dirty-full) floats | [AliExpress](https://www.aliexpress.us/w/wholesale-ky-003.html) / [Amazon](https://www.amazon.com/s?k=ky+003) / [eBay](https://www.ebay.com/sch/i.html?_nkw=ky+003) |
| | 4 | $0.10 | Magnets for hall sensors, size TBD | [AliExpress](https://www.aliexpress.us/w/wholesale-neodymium-magnet.html) / [Amazon](https://www.amazon.com/s?k=neodymium+magnet) / [eBay](https://www.ebay.com/sch/i.html?_nkw=neodymium+magnet) |
| Dust container | 1 | n/a | 3D printed |  |
| Dock exhaust filter | 1 | 3-8? | Washable/HEPA |  |
| Suction port + gasket | 1 | 2-5 | Need a good seal |  |
| Clean + dirty water tanks | 1 | n/a | 3D printed, removable |  |
| Wash tray | 1 | n/a | 3D printed, removable, w/scrub ribs |  |
| Tubing, fittings, seals, gaskets, fasteners | 1 | 5-10? |  |  |
| Blower fan | 1 | 3-8? | Ambient air, no heater for now |  |
| ~PTC heater + thermal fuse + thermistor~ | ~1~ | ~8-20~ | Not in first model. ~Needs redundant thermal cutoff~ |  |
| Duct, alcove, ramp, housing | 1 | n/a | 3D printed |  |
| Charging contacts | 2-4 | 2-6? | Gold-plated pogo pins ≥4A; rear-vertical, above water line | |

> *Fan sourcing caveat:* the *kPa is the fan's own rating* — verify it against the fan's
> model number / datasheet. The vacuum models are a *sourcing search aid only*: a fan listed
> as "fits vacuum X" is *not* necessarily X's original fan (lower-power replacements are sold as
> compatible for higher-suction models). Omit any model whose known suction contradicts the row.

Three dock tiers share one robot base, released in order:

| Tier | Adds | Rough extra parts |
|---|---|---|
| Basic charge (first release) | charging only | printed housing + contacts/magnets + wall adapter + IR beacon |
| Auto-empty | dust auto-emptying | dock fan + bin/bag + sealed port |
| Auto-empty + wash + dry | mop wash + hot-air dry | clean + dirty tanks, 2 pumps, heater + fan, own ESP32 + WiFi controller |

## Sourcing strategy

- Print geometry, source mechanisms and wear items. See the print-vs-source table in
  [docs/design-document.md](docs/design-document.md#2-print-vs-source-strategy).
- Spec wear parts (brushes, filters, wheel modules) in *common, abundant sizes* so
  builders can buy cheap universal replacements anywhere.
- Per-module sourcing details will land in the relevant
  [contributions/](contributions) RFCs as they mature.

## How I calculate BoM costs

Prices for vacuum cleaner aftermarket parts have a wide spread (3x max/min as a ballpark).
You can buy same part for, say, $15 or $30 or even $45.

Therefore, if you search [AliExpress](https://www.aliexpress.us/w/wholesale-roborock-s5-lidar.html)/eBay/Amazon
for, say, "Roborock S5 LiDAR", you will likely see offers around $30.

There will probably several pages worth of those offers. And if you dig through those pages, you will probably start
finding parts for $25.

If you are shopping on AliExpress, open a part listing and check for free coupon offers like "$2.00 off on $18.00".
That brings your $25 price down to $23. Also, check the fine print in red font saying something like "$21.43 each, ≥ 3 pieces".

That's not the end of it. The next AliExpress trick is to wait for seasonal sales and promotions. Those happen relatively often.
Sales and promotions can bring prices down even futher.

How can you get to the rock-bottom $15 price? Aftermarket parts prices depend on your search keywords.
Try searching for multiple keyword variations: "Roborock S5 LDS", "Roborock S5 LiDAR", "original laser distance lds",
"LDS02RR", "LDS02RR LiDAR", "Roborock LDS02RR", "LDS laser sensor for xiaomi Roborock" and so on. Be creative and persistent.
Try searching Google "site:aliexpress.com lds02rr" and other variations. Be creative and persistent.

Combining all these methods is how you can get the rock bottom $15 price.

I record two prices for each part in the BoM table, for example "$15-$25".
The first ($15) price is the rock bottom one that often requires a minimum purchase of 3 pieces - what I'd (or anyone) be paying putting together an OOMWOO all-parts-included convenience kit.
The second ($25) price is what you can realistically get when purchasing 1 piece, *applying coupons* and doing *a few minutes of search*.

Why record the first price if requires a 3 pcs minimum? This is because I intend to assemble a convenient parts kit - and make it available to everyone.

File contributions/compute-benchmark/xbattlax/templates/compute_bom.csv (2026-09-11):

hardware_profile | role | part | sku_or_module | quantity | unit_price | currency | regional_source_url | stock_status | power_notes | cooling_notes | storage_or_carrier_notes | notes
CM4_4GB | compute | Compute Module 4
CM5_4GB | compute | Compute Module 5
Pi4_4GB | compute | Raspberry Pi 4 4GB
TwoGB_stretch | compute | 2GB SBC or module
Consumer_MCU | safety_controller | STM32G473VCT6
Educational_ESP32 | micro_ros_bridge | ESP32 board

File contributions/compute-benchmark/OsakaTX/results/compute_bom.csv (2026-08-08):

hardware_profile | role | part | sku_or_module | quantity | unit_price | currency | official_source_url | stock_status | power_notes | cooling_notes | storage_or_carrier_notes | notes
CM4_4GB | compute | Compute Module 4 4GB (Lite or eMMC variants) | CM4 | 1 | 41.25 | USD | https://www.raspberrypi.com/products/compute-module-4/ | official page: 'starting from as low as $41.25'; regional street price + stock = record at purchase time |  | passive OK for MY02; recommend 5V supply sized on load | eMMC Lite option depends on carrier (oomwoo-io-board) | Cortex-A72 1.5GHz,1/2/4/8GB LPDDR4-3200; in production 'until at least January 2034' (fetched 2026-08-04)
CM5_4GB | compute | Compute Module 5 2GB | CM5 | 1 | 67.50 | USD | https://www.raspberrypi.com/products/compute-module-5/ | official page: 'available now from $67.50'; regional street price + stock = record at purchase time | active cooling recommended under sustained load (27W dev kit PSU class) | 2/4/8/16GB LPDDR4-4267 w/ ECC; eMMC 0/16/32/64GB | BCM2712 Cortex-A76 2.4GHz; in production 'until at least January 2036' (fetched 2026-08-04)
Pi4_4GB | compute | Raspberry Pi 4 Model B 4GB | Pi4 | 1 | 35.00 | USD | https://www.raspberrypi.com/products/raspberry-pi-4-model-b/ | official page: 'From $35' (entry variant); 4GB variant higher; regional + stock = record at purchase time | 15W USB-C supply recommended (official page); passive case OK | SD card storage | RAM variants 1/2/4/8GB (fetched 2026-08-04)
Pi4_2GB_stretch | compute | Raspberry Pi 4 Model B 2GB | Pi4 | 1 |  | USD | https://www.raspberrypi.com/products/raspberry-pi-4-model-b/ | provisional 2GB-class stretch target; price/stock unverified this run | 15W USB-C supply recommended | SD card storage | 2GB variant = the module's 2GB-class stretch baseline target
Pi5_16GB | compute | Raspberry Pi 5 16GB | Pi5 | 1 | 305.00 | USD | https://www.raspberrypi.com/products/raspberry-pi-5/ | official page: 'Raspberry Pi 5 16GB is available now for $305'; treat as cost ceiling only, default target is Pi4/CM4-class | active cooling recommended | microSD | cost ceiling for compute BOM (fetched 2026-08-04)
Consumer_MCU | safety_controller | STM32G473 (selected base controller) | STM32G473 | 1 |  |  | https://github.com/makerspet/oomwoo | MCU price/stock unverified this run; record at purchase time | MCU owns motors/safety/watchdogs per oomwoo-io-board SPEC |  |  | selected MCU supersedes STM32G070; see upstream README + module README
Educational_ESP32 | micro_ros_bridge | ESP32 board (educational profile only) | ESP32 | 1 |  |  | https://www.espressif.com/en/products/socs/esp32-s3 | educational/offboard ROS2 profile; not consumer autonomous vacuum compute | ESP32-S3-class MCU, 240MHz, 512KB SRAM |  |  | educational profile per issue #18; not a Nav2/SLAM host

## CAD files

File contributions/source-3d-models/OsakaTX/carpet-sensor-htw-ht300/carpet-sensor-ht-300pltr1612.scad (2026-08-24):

// Carpet / Material-Recognition Sensor — HTW HT-300PLTR1612-1-class 300 kHz
// ultrasonic transducer (OOMWOO BOM "Carpet sensor — Ultrasonic 300kHz")
// ===========================================================================
//
// Parametric clearance/interfacing model of the 300 kHz ultrasonic transducer
// used by OOMWOO as the carpet/material-recognition sensor.
//
// BOM identity (verify against the actual unit before relying on fit):
//   BOM.md row "Carpet sensor | 1 | $6-12 | Ultrasonic 300kHz | Low
//   availability retail ... purchase factory direct instead". The BOM does not
//   name a part number; the class of part is a ~300 kHz ultrasonic material /
//   carpet recognition transducer with a single enclosed transceiver element.
//
// Dimension basis — TWO independently fetched primary sources (2026-08-11):
//
//   S1: HTW (Chengdu Huitong West-Electronic) HT-300PLTR1612-1 product listing,
//       Made-in-China.com. Spec table verbatim:
//         "Diameter | mm | 16"
//         "Height  | mm | 12"
//         "Working mode | -- | Transceiver"
//         "Nominal frequency | KHz | 290±15"
//         "Directivity | Deg | ≤12°"
//         "Capacitance | pF | 1300±20%"
//         "Target distance | mm | 30"
//         "Precision | mm | ≤2mm"
//         "Housing | / | PC"
//       Product attributes: "Specification: diameter-16mm wire-60mm",
//       "Probe type: Dual Probe", "IP67", "RoHS".
//       URL: https://htwsensor.en.made-in-china.com/product/xfUrtLydvQhb/
//       ...-Ultraosinc-Sensor-Transducer.html  (fetched 2026-08-11)
//       Price US$6.00 @20-199 pcs — matches BOM $6-12.
//
//   S2: ISSRSensor ISUB30-16GK12 300 kHz ultrasonic material sensor,
//       issrsensor.com product page + selection manual naming grid:
//         - ISSR naming grid decodes "ISUB30-16GK12" as:
//           IS=ISSR, U=Ultrasonic, B=Basic, 30=30mm range,
//           16="Tube diameter 16mm", GK="Plastic shell", 12="Shell length 12mm"
//           -> body Ø16 × L12, matching S1.
//         - Spec table verbatim: "Detection Range | 30 ± 1 mm",
//           "Beam Angle | ±5°", "Sensor Frequency | Approx. 300 kHz",
//           "Operating Voltage | 5 V DC, ripple ≤ 10% Vpp",
//           "No-Load Current | ≤ 11 mA", "Ingress Protection Rating | IP65",
//           "Connection Type | VC connector, 1.25 mm pitch terminal,
//           A1251H-4P/CJT".
//       URL: https://issrsensor.com/products/ultrasonic-material-sensor-
//       300khz-robotic-vacuum/  (fetched 2026-08-11)
//
//   The two vendors describe the SAME class of part (300 kHz ultrasonic floor
//   material recognition transducer, Ø16 × 12mm). Treat the body envelope
//   (Ø16 × 12) as datasheet-confirmed; everything else marked (estimate) must
//   be caliper-verified against the physical unit (MEASURE-ME.md §16).
//
// Cross-axis convention: body axis along Z, sensing face pointing DOWN (−Z),
// wire exiting the TOP (+Z). Origin at body axis at the sensing face plane.
//
// STATUS: DRAFT — datasheet-grounded envelope, caliper verification required.
//
// License: CC BY-SA 4.0

$fn = 64;

/* [Dimensions — EDIT TO MATCH YOUR MEASURED PART] */

// --- Body envelope ---
body_dia = 16.0;   // (datasheet: HTW spec "Diameter | mm | 16"; ISSR naming
                   //  decode "16 = Tube diameter 16mm")
body_h   = 12.0;   // (datasheet: HTW spec "Height | mm | 12"; ISSR naming
                   //  decode "12 = Shell length 12mm")

// --- Sensing face (bottom, −Z) ---
// The emitting surface sits recessed inside a plastic housing; the exact
// recess depth / active aperture are not published.
face_recess   = 2.0;   // (estimate) recess of active element below face plane
active_dia    = 12.0;  // (estimate) active element aperture Ø (smaller than body)
face_dome_t   = 0.8;   // (estimate) plastic dome thickness over element

// --- Wire / cable exit (top, +Z) ---
wire_dia  = 1.5;   // (estimate) wire Ø (unpublished; typical for this class)
wire_len  = 60.0;  // (datasheet: HTW attributes "wire-60mm")
// ISSR variant uses a 1.25mm-pitch VC connector (A1251H-4P/CJT) instead of a
// bare wire — see MEASURE-ME §16 row 9 to confirm which termination you have.

// --- Mounting / retention ---
// No mounting flange is published for either source. These transducers are
// normally retained by a rubber grommet / interference fit into an Ø16-ish
// bore, or adhered. Modeled as plain cylinder; the fit jig
// (jigs-new/carpet-sensor-fit.scad) tests bore retention.
bore_clearance = 0.6;   // (estimate) diametral clearance in the printed mount
retain_collar_h = 3.0;  // (estimate) height of interference band used in jig

// ===== MODULES =====

module transducer_body() {
    color("#3a3a3a", 0.9) {
        translate([0, 0, 0])
            cylinder(d = body_dia, h = body_h);
    }
}

module sensing_face() {
    // Recessed active element + plastic dome at the −Z face.
    // Active element (cavity):
    color("#222222") {
        translate([0, 0, face_recess])
            cylinder(d = active_dia, h = body_h - face_recess);
    }
    // Dome over the element (thin plastic disc flush with body):
    color("#dddddd", 0.85) {
        translate([0, 0, 0])
            cylinder(d = active_dia, h = face_dome_t);
    }
}

module wire_lead() {
    // Cable exiting the top face (+Z), centered on axis. Marked (estimate)
    // for the Ø/slack; length per HTW "wire-60mm".
    color("#cc2222", 0.9) {
        translate([0, 0, body_h])
            cylinder(d = wire_dia, h = wire_len);
    }
}

module rough_mount_band() {
    // Visual-only interference band (no geometry): retained by grommet at the
    // collar height region. Drawn as a thin raised rib on the upper body.
    color("#666666") {
        translate([0, 0, body_h - retain_collar_h])
            difference() {
                cylinder(d = body_dia + 0.4, h = 1.0);
                cylinder(d = body_dia - 0.4, h = 1.1);
            }
    }
}

// ===== ASSEMBLY =====
transducer_body();
sensing_face();
wire_lead();
// rough_mount_band();  // uncomment if you want the visual retention rib

// ===== NOTES =====
// - If you buy the HT-300PLT-A / -M / -MIR variants (with embedded PCBA), a
//   PCB/daughterboard extends the envelope beyond this bare-transducer
//   cylinder — measure it and add a module below (MEASURE-ME §16 rows 10-11).
// - The ISSR ISUB30-16GK12 uses a 1.25mm-pitch VC plug (A1251H-4P/CJT) rather
//   than this model's bare wire — confirm termination before committing a
//   wire-routing channel in the chassis.

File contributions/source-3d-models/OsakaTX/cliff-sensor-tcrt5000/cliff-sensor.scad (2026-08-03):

// Cliff Sensor Module — TCRT5000 Reflective Optical Sensor
// iRobot Roomba 500/600/700/800/900 series — as used in OOMWOO BOM
//
// Datasheet-confirmed (TCRT5000 bare component):
//   10.2 x 5.8 x 7.0 mm (L x W x H)
// Module PCB dimensions (estimate, based on generic "MH sensor" module):
//   20 x 10 x 1.6 mm PCB + through-hole components
//
// Licensed CC0 — use freely.

// ===== PARAMETERS =====

// ---- Datasheet (TCRT5000 bare component) ----
sensor_l    = 10.2;  // mm (datasheet: Vishay TCRT5000 L dimension)
sensor_w    =  5.8;  // mm (datasheet: Vishay TCRT5000 W dimension)
sensor_h    =  7.0;  // mm (datasheet: Vishay TCRT5000 H dimension)

// ---- Module PCB (estimate: generic MH-style breakout) ----
pcb_l       = 35;    // mm (estimate: common TCRT5000 module board length)
pcb_w       = 10;    // mm (estimate: common TCRT5000 module board width)
pcb_thick   =  1.6;  // mm (estimate: standard FR4 1.6mm)
pcb_z_base  =  0;    // mm — reference plane

// ---- Mounting hole (estimate) ----
mount_hole_dia = 2.5; // mm (estimate: M2 screw clearance)
mount_hole_ofs_x = 3; // mm (estimate: hole center from board edge)

// ---- Pins (through-hole, bend or straight) ----
pin_count   =  4;    // (datasheet: emitter A/C + detector C/E)
pin_spacing =  2.54; // mm (estimate: standard 0.1" header pitch)
pin_dia     =  0.64; // mm (estimate: typical header pin)
pin_length  = 12;    // mm (estimate: exposed pin below PCB)

// ---- Comparator (LM393 on some modules — estimate) ----
comp_w      =  5;    // mm (estimate: SOIC-8 body width)
comp_l      =  5;    // mm (estimate: SOIC-8 body length)
comp_h      =  1.75; // mm (estimate: SOIC-8 height above PCB)
comp_ofs_x  =  6;    // mm (estimate: from PCB edge)
comp_ofs_y  =  0;    // mm (estimate: centered on PCB width)

// ---- Potentiometer (threshold adjust — estimate) ----
pot_dia     =  6;    // mm (estimate: 3296W trimmer pot diameter)
pot_h       =  4;    // mm (estimate: pot height above PCB)
pot_ofs_x   = 20;    // mm (estimate: along board)
pot_ofs_y   =  0;    // mm (estimate: centered)

// ---- Resistor network ----
r_width     =  1.6;  // mm (estimate: 0805 SMD resistor)
r_length    =  2.0;  // mm (estimate)
r_height    =  0.5;  // mm (estimate)

// Detection area marker (the sensor looks downward through this)
detect_offset_y =  0;  // mm — centered on board
detect_offset_z = -0.5; // mm — below PCB bottom (flush or slightly proud)

$fn = 16;

// ===== MODULES =====

module sensor_body() {
    // Vishay TCRT5000 in leaded package — the actual optosensor
    // Positioned at one end of the PCB, facing downward (-Z)
    // Centered on PCB midline
    color("DimGray") {
        translate([0, -sensor_w/2, pcb_thick])
            cube([sensor_l, sensor_w, sensor_h]);
    }
}

module pcb_board() {
    // FR4 PCB substrate
    color("DarkGreen", 0.85) {
        difference() {
            translate([0, -pcb_w/2, pcb_z_base])
                cube([pcb_l, pcb_w, pcb_thick]);
            // Mounting hole
            translate([mount_hole_ofs_x, 0, -0.1])
                cylinder(h=pcb_thick + 0.2, d=mount_hole_dia, $fn=12);
            translate([pcb_l - mount_hole_ofs_x, 0, -0.1])
                cylinder(h=pcb_thick + 0.2, d=mount_hole_dia, $fn=12);
        }
    }
}

module header_pins() {
    // 4 pins protruding below PCB — for socket or soldering
    for (i = [0 : pin_count - 1]) {
        translate([sensor_l + 8 + i * pin_spacing, 0, -pin_length])
            cylinder(h=pin_length, d=pin_dia, $fn=8);
        // Pin shoulder above PCB
        translate([sensor_l + 8 + i * pin_spacing, 0, pcb_thick])
            cylinder(h=2, d=pin_dia * 1.2, $fn=8);
    }
}

module comparator_ic() {
    // LM393 comparator (present on "MH" type modules)
    translate([comp_ofs_x, -comp_l/2, pcb_thick]) {
        color("Black")
            cube([comp_w, comp_l, comp_h]);
        // Pin legs
        for (ix = [0, 1])
            for (iy = [0, 1])
                translate([0.5 + ix * (comp_w - 1), 0.5 + iy * (comp_l - 1), -0.5])
                    cylinder(h=0.5, d=0.45, $fn=6);
    }
}

module potentiometer() {
    // Trimmer pot for sensitivity adjustment
    translate([pot_ofs_x, -pot_dia/2, pcb_thick]) {
        color("Blue")
            cylinder(h=pot_h, d=pot_dia);
    }
}

module smd_resistors() {
    // A few SMD resistors for circuit completion
    for (i = [0 : 3]) {
        translate([12 + i * 3, -pcb_w/2 + 2 + (i % 2) * 3, pcb_thick])
            color("Tan")
                cube([r_length, r_width, r_height]);
    }
}

module detection_cone() {
    // Visual indicator of the IR detection area (transparent cone)
    // Not for printing — just for reference in CAD
    translate([sensor_l/2, 0, -3]) {
        %cylinder(h=2, d1=sensor_w, d2=8, $fn=12);
    }
}

// ===== ASSEMBLY =====

module cliff_sensor() {
    pcb_board();
    sensor_body();
    header_pins();
    // Note: not all modules have all these components
    // Comment/uncomment as needed for your specific module
    // comparator_ic();
    // potentiometer();
    // smd_resistors();
    // detection_cone();
}

// ===== RENDER =====
cliff_sensor();

// ===== NOTES =====
// (1) Roomba cliff sensor modules typically have 4 wires (VCC, GND, signal).
//     The TCRT5000 itself has 4 pins (emitter A,C — detector C,E).
//     The sensor module often adds an LM393 comparator + potentiometer
//     for digital threshold output.
//
// (2) Roomba uses 4 cliff sensors (front-left, front-right, rear-left,
//     rear-right) mounted at the edges of the chassis, directed downward
//     at ~20-30° from vertical.
//
// (3) BOM: 4x cliff sensors bundle (AliExpress ~$1.50-2.50 each), includes
//     2x bumper switches. MEASURE actual module variant received.

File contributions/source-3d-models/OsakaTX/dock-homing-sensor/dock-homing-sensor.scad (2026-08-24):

// Dock Homing Sensor PCB — 2x TSOP38238 IR Receivers
// BOM (upstream BOM.md line 57): "Dock homing sensor | 1 | $3 | Custom PCB |
// 2x TSOP38238 IR receivers"
//
// Function: robot-side receiver board for the final dock-approach/centering
// step. The DOCK board carries an "IR homing beacon" (BOM.md line 81, Dock
// board feature). The robot's TWO TSOP38238 receivers detect that beacon and
// the pair gives lateral (left/right) signal-parity information so the MCU can
// steer the robot onto the charge contacts. This model carries NO IR LED —
// the dock emits, the robot receives. (Function reasoning: (estimate) inferred
// from BOM lines 57 + 81; verify intended firmware use.)
//
// TSOP38238 envelope is (datasheet: Vishay TSOP382/384 datasheet, rev 2.1,
// 27-May-2025, Doc. 82491, fetched 2026-08-15): Minicast package
// "5.0 W x 6.95 H x 4.8 D" mm, leads 2.54 mm nominal pitch, overall length
// with leads 8.25 ± 0.3 mm, pinning 1 = OUT, 2 = GND, 3 = VS, carrier 38 kHz,
// half-angle half transmission distance φ1/2 = ±45 °.
//
// Everything PCB-outline and layout related below is (estimate) — this is a
// custom PCB, not an off-the-shelf module.
//
// Licensed CC0 — use freely.

// ===== PARAMETERS =====

// ---- Custom PCB (estimate, conjectural layout) ----
pcb_l      =  25;   // mm (estimate) board length along boresight (dock-facing edge ⇒ rear edge)
pcb_w      =  26;   // mm (estimate) board width across the robot (cross-axis); sized to
                    //   contain the receiver pair + margins (2 x tsop_w + rx_pitch + edges)
pcb_thick  =   1.6; // mm (estimate) standard FR4, verify with Jig 16 feeler steps

// ---- TSOP38238 (datasheet: Vishay TSOP382/384, Doc 82491, fetched 2026-08-15) ----
tsop_w     =   5.0; // mm (datasheet) package W
tsop_d     =   4.8; // mm (datasheet) package D (depth along boresight)
tsop_h     =   6.95; // mm (datasheet) package H total (leaded Minicast; overall w/ leads 8.25 ± 0.3)
tsop_pins  =   3;   // (datasheet) pinning 1 = OUT, 2 = GND, 3 = VS
tsop_pin_pitch = 2.54; // mm (datasheet) lead pitch "2.54 nom."

// ---- Receiver pair geometry (estimate — THE critical docking dimension) ----
rx_pitch   =  16;   // mm (estimate) center-to-center spacing of the two TSOP38238.
                    // Sets the lateral centering geometry vs. the dock beacon.
                    // Constraints: ≤ dock beacon beam width at approach; ≥ PCB
                    // space for two full packages + leads. MUST be re-derived
                    // from the actual dock/IR design and beam test.
rx_inset   =   4;   // mm (estimate) first receiver center from board front edge

// ---- Mounting / connector (estimate) ----
mtg_dia    =   2.5; // mm (estimate) M2 screw clearance
mtg_inset  =   2.5; // mm (estimate) mount hole center from rear board edge
conn_pins  =   4;   // (estimate) VCC, GND, OUT_beam1, OUT_beam2 (2 receivers share supply)
conn_pitch =   2.0; // mm (estimate) JST PH 2.0 mm or similar
conn_w     =   8;   // mm (estimate) connector shell width
conn_d     =   7;   // mm (estimate) connector shell depth
conn_h     =   6;   // mm (estimate) connector shell height above PCB

$fn = 16;

// ===== MODULES =====

module pcb() {
    color("DarkGreen", 0.85) cube([pcb_l, pcb_w, pcb_thick]);
}

module tsop38238(at_y = 0) {
    // Dash-mounted IR receiver module. Window faces +X (toward the dock).
    color("DimGray") {
        translate([rx_inset, at_y - tsop_w/2, pcb_thick])
            cube([tsop_d, tsop_w, tsop_h]);
        // IR window on the +X (boresight) face, capped on both sides by case
        color("DarkRed", 0.6)
            translate([rx_inset + tsop_d, at_y - 1.0, pcb_thick + 1.0])
                cube([0.3, 2.0, tsop_h - 2.0]);
        // 3 leads (1=OUT,2=GND,3=VS) down through the PCB, 2.54 pitch
        for (i = [0 : tsop_pins - 1]) {
            translate([rx_inset + 2, at_y + (i - 1) * tsop_pin_pitch, -2.5])
                cylinder(h = pcb_thick + 2.5 + 1, d = 0.6, $fn = 6);
        }
    }
}

module connector() {
    // 4-pin JST PH or similar on the rear (-X) edge
    color("White") {
        translate([-conn_d, pcb_w/2 - conn_w/2, pcb_thick])
            cube([conn_d, conn_w, conn_h]);
        for (i = [0 : conn_pins - 1]) {
            translate([-conn_d + 1.5 + i * conn_pitch, pcb_w/2, pcb_thick + conn_h/2])
                cylinder(h = 1, d = 0.5, $fn = 6);
        }
    }
}

module mounting_holes() {
    // 2 rear mount holes (M2) on the board centreline
    for (x = [pcb_l - mtg_inset])
        for (y = [pcb_w/2])
            translate([x, y, -0.1])
                cylinder(h = pcb_thick + 0.2, d = mtg_dia, $fn = 12);
}

module assembly() {
    difference() {
        union() {
            pcb();
            tsop38238( at_y =  pcb_w/2 - rx_pitch/2);
            tsop38238( at_y =  pcb_w/2 + rx_pitch/2);
            connector();
        }
        mounting_holes();
    }
}

// ===== RENDER =====
assembly();

// ===== NOTES =====
// (1) BOM hierarchy: the two TSOP38238 are the ONLY compass co-located with
//     this board (BOM L57). The dock emits a homing beacon (BOM L81); both
//     receivers point +X and are spaced rx_pitch apart so centered access sees
//     equal irradiance and off-center approach creates a left/right imbalance
//     (φ1/2 = ±45° per datasheet gives each receiver a wide acceptance cone —
//     verify actual beacon geometry).
//
// (2) rx_pitch is the single most important number on this board (like
//     contact_pitch on the charging contacts). It sets how precisely the robot
//     can square to the dock. If firmware uses only "beacon seen / not seen",
//     spacing only needs to clear the charge contact pitch (45 mm est) gap so a
//     receiver is always within the beacon cone; if firmware steers on signal
//     parity, wider spacing = sharper centering but a narrower capture window.
//     Re-derive it from the dock IR design, don't trust this 16 mm estimate.
//
// (3) No IR LED on this board — the dock beacon (BOM L81) is the emitter.
//     Screened/ sleeved against ambient light if the beacon is the only gate
//     for parking (datasheet gives automatic AGC suppression of fluorescent
//     lamp noise; still verify in a sunlit room).
//
// (4) This is a placement/clearance draft. The PCB layout (25 mm long x 26 mm
//     wide) is conjectural — fabricate a real board and feed measurements back so the
//     outline/pocket geometry stops being estimate. See MEASURE-ME §18 and
//     Jig 16.

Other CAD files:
contributions/source-3d-models/OsakaTX/hepa-filter-cartridge/hepa-robot-vacuum-filter.scad
contributions/source-3d-models/OsakaTX/battery-pack-brr-2p4s/brr-2p4s-5200.scad
contributions/source-3d-models/OsakaTX/charging-contacts/charging-contacts.scad
contributions/source-3d-models/OsakaTX/cjwp12-water-pump/cjwp12-water-pump.scad
contributions/source-3d-models/OsakaTX/dock-auto-empty-fan/dock-auto-empty-fan.scad
contributions/source-3d-models/OsakaTX/dock-water-pump-24v/dock-water-pump-24v.scad
contributions/source-3d-models/OsakaTX/hepa-filter-cartridge/jig25-filter-id-gauge.scad
contributions/source-3d-models/OsakaTX/jigs-new/battery-pocket-fit.scad
contributions/source-3d-models/OsakaTX/jigs-new/carpet-sensor-fit.scad
contributions/source-3d-models/OsakaTX/jigs-new/charger-strip-slot-gauge.scad
contributions/source-3d-models/OsakaTX/jigs-new/cjwp12-pump-gauge.scad
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

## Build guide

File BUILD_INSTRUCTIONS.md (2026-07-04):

# Build Instructions

> *Not available yet — this is a placeholder.*
>
> OOMWOO is currently at the *design / RFC stage*, not the build-it-yourself stage.
> Step-by-step build instructions will arrive once the first
> [Bill of Materials](BOM.md) and parts are validated (*first BoM targeted ~mid-July*)
> and the modules are proven on real hardware.

## Where the project is right now

- *Design + interfaces:* [ARCHITECTURE.md](docs/ARCHITECTURE.md)
- *Parts list (draft):* [BoM.md](BOM.md)
- *Modules being built (RFCs):* [README → Requests for Contributions](README.md#requests-for-contributions)
- *Design decisions + research:* [docs/design-document.md](docs/design-document.md)

## What you can do now

- *Star / watch* the repo to follow along — that's the best way to know when build
  instructions land.
- *Contribute:* pick a module from the [RFC list](README.md#requests-for-contributions)
  and dive in — every skill level welcome.
- *Join the community:* [Discord](https://discord.gg/3y2JKz5T25) and
  [GitHub Discussions](https://github.com/makerspet/oomwoo/discussions).
- *Follow the build in public:* [YouTube](https://www.youtube.com/@makerspet).

## What this page will become

A complete, zero-to-hero guide: sourcing the parts, printing the chassis, assembling the
robot, flashing the firmware, bringing up ROS2, and first clean — with photos and videos.
We'll make it a clear, standalone guide the moment there's something to build.

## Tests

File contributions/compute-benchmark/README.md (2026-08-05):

# Compute Benchmark & Memory Reduction

Measure whether OOMWOO can keep ROS2/Nav2/SLAM onboard while reducing the
minimum compute target from a comfortable 4 GB class system toward a practical
2 GB class system.

This module is for repeatable measurements, not guesses. It should help compare
Python/C++ ROS2 nodes, ROS2 composable-node layouts where supported, process
layout changes, and later optional Rust experiments under the same workload.

> Status: in progress. Use the ROS2 Jazzy development container and the current
> simulation stack where possible. Hardware runs on Pi 4, CM4, CM5, or compatible
> modules are especially useful when available.

## Current Working Assumptions

- The consumer vacuum profile keeps SLAM and navigation onboard.
- The practical near-term target is Pi 4 / CM4-class compute with 4 GB RAM.
- The stretch target is to reduce the minimum memory requirement toward 2 GB
  without giving up ROS2.
- The compute-module direction is CM4/CM5 or compatible modules on a carrier
  board; ignore the older RK3562 reference path.
- The MCU owns motors, sensors, safety, battery/charging supervision, watchdogs,
  and the custom serial protocol.
- STM32G473 is the selected base-controller MCU, superseding the earlier
  STM32G070 candidate.
- The MVP 2D LiDAR target is 5 Hz with no scan dropping.
- Rust/rclrs is an optional late-summer integration candidate, not a baseline
  dependency today.

Context: this module follows the compute discussion in
[issue #18](https://github.com/makerspet/oomwoo/issues/18).

## Request For Contribution

Submit a benchmark contribution under:

```text
contributions/compute-benchmark/<your-github-username>/
```

Include:

- a reproducible benchmark plan
- scripts that capture RSS/PSS/CPU/startup timing where possible
- a hardware/software run matrix
- a compute BOM table with regional price and stock fields
- clear notes on ROS distro, RMW, hardware, RAM size, LiDAR rate, and scenario
- a short decision record after measurements

## Metrics

Minimum useful metrics:

| Metric | Why it matters |
|---|---|
| RSS/PSS per process | Shows where memory is actually going. |
| CPU idle / mapping / navigation | Separates always-on cost from workload cost. |
| Startup time | Exposes heavy node initialization and launch overhead. |
| LiDAR update rate | Confirms the benchmark is not cheating by dropping scans. |
| Nav2/SLAM headroom | Determines whether 2 GB is plausible with ROS2 retained. |
| Recovery-event latency | Keeps safety-adjacent nodes honest under optimization. |

## Strategies To Compare

1. Current Python/C++ baseline.
2. ROS2 composable nodes where supported, plus launch/process layout changes.
3. C++/rclcpp for selected hot or always-on custom nodes.
4. Optional Rust/rclrs spike for selected custom nodes after dev-image setup is
   reproducible.

Rust should only move from optional to recommended if it demonstrates a useful
RSS/PSS or latency improvement and does not make the default Jazzy developer
experience fragile.

## Acceptance Criteria

- Measurements are reproducible by another contributor.
- The benchmark records hardware, RAM, ROS distro, RMW, scenario, and git SHA.
- Results distinguish process RSS from PSS when PSS is available.
- Benchmarks do not reduce LiDAR update rate below the target unless explicitly
  marked as an experiment.
- The contribution explains whether the result supports 4 GB only, 2 GB as a
  stretch target, or a different hardware class.
- BOM notes include module/board, carrier, power, cooling, storage, MCU add-ons,
  regional price, and stock status.

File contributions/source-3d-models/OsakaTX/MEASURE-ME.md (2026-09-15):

# MEASURE-ME — dimensions and states that gate the CAD models

OsakaTX has a caliper; these are the checks to run, then report back so the
models get corrected. Rows gated on **identity** come first per section.
Status values: `unverified` (never measured), `measured` (value stated with
provenance), `n/a`.

**2026-09-06 change summary** — §1 row 4 rewritten around the IKsares drive-wheel
merge (pinion OD closed, replaced by the first-stage centre distance; wheel
bore reworded to the output-shaft wheel seat; later-stage module row added);
rows 1–3 unchanged in substance; jigs 19–20 rows moved into §1 as rows 11–12
so the section is self-contained; §22 gains row 13 (motor-can dims, flange
unmodeled); `dims-tally.py` audit script added (counts `[M]`/`(estimate)`
provenance tags across the SCAD models).

Legend: ⛔ identity gate · Ω measured elsewhere, cross-check · † jig exists.

Bounds marked (est.) in the Expected column are derived from merged upstream
part-specs data, not measured on site — they exist so a wrong caliper reading
is caught, not to pre-empt the measurement.

## 1. Roborock S5-family drive wheel — the aftermarket IKsares-measured type

Model: `roborock-s5-drive-wheel/drive-wheel.scad` (v2, rebuilt from merged
`part-specs/IKsares/drive-wheel/README.md` — 65.36:1 train, Ø27.5×44.3 motor,
71.5 wheel). The electrical/pinout side there is settled; what still gates the
CAD is mechanical, and mostly one session with the module assembled:

| #  | What to measure | Model value today | Expected (cross-check) | Status |
|----|---|---|---|---|
| 1  | ⛔ Confirm the unit in hand matches the measured part: motor can marking `GM-RS360-16248` + 7-pin 1.5 mm-pitch connector | — | IKsares pinout photos  | unverified |
| 2  | Wheel OD at tread peak | 71.5 mm [M from #61] | 71.5 | measured (IKsares) |
| 3  | Wheel tread width (rubber, incl. crown) | 24 mm (E) | (est.) 20–30 class | unverified |
| 4  | **Stage-1 centre distance** motor-shaft → 36T wheel-shaft `a = mn·(z1+z2)/(2·cos β)`: 11.75 (spur .5)/12.50 (β20°)/12.97 (β25°)/13.24 (β27.5°)/13.57 (β30°) — one reading fixes β and the whole stage-1 geometry | 13.24 mm [M1] via β=27.5° | 11.75–13.57 spread | unverified |
| 4b | Pinion OD calibration: caliper across one tip + opposite two tips reads 0.980·De at z=11; De(expected)=7.07–7.35 from β band; measured 7.00 was the uncorrected read | implicit in β | 6.93–7.20 caliper-read band | measured (IKsares §3) |
| 5  | Wheel hub diameter under the rubber | 44 mm (E) | — | unverified |
| 6  | **Wheel-side input Ø** — bore/spline/D-shaft where the 24T output gear drives the wheel (unrelated to the motor's Ø2.2 shaft; the wheel is driven from the output side) | Ø8 bore (E) | — | unverified |
| 7  | Wheel-axle stub length beyond the gearbox face (offset `wheel_x` in the model) | 6 mm face-half + 6 (E) | — | unverified |
| 8  | Rear envelope: ring carrier + solder tabs proud of the Hall PCB — max depth behind the 34.0 mm can | 1.5 mm (E) | >0, unquantified in #61 | unverified |
| 9  | Later-stage normal modules (13/42, 12/34, 11/24 stages); stagger vs the 0.5 first stage | 0.8 single value (E) | (est.) 0.5–1.0 | unverified |
| 10 | Face width per stage; helical vs spur for stages 2–4 | 3.0 mm, spur (E) | (est.) | unverified |
| 11 | † JST ZH 1.5-connector: 9.0 mm row pitch / 1.5 pin pitch / housing W×H — reuse `jigs-new/zh1.5-harness-gauge.scad` (§ jig below); IKsares measured 9.0/6 = 1.5 pitch on the module, housing dims remain vendor-confirmation for the mating part | gauge cut 1.5 mm | 1.5 mm pitch [M] | measured (pitch, IKsares) |
| 12 | † Gear-motor face: 2 ✕ front screws — spacing, thread, head dia (mounting interface) | unmodeled | — | unverified |

Once row 4 lands: stage-1 centre distance + β fix gear-1 PD/tip; row 9 then
follows from gear-tip calipers on stages 2–4 (same session).

### Jig (new this cycle): 7-way 1.5 mm harness gauge

`jigs-new/zh1.5-harness-gauge.scad` — printable single-set go/no-go for the
drive-wheel harness plug: `pin_row_1_7(len=9.0)` row, a `gauge_plate()` with
7 slots on 1.5 mm, and `lug(theta=50, depth=1.0)` latch corners. Base grid
inherited from `jigs-new/baseline_grid.scad` (per min in the header there).
Print, plug the harness: pins slide, latches catch = pitch confirmed
(IKsares measured it; the jig is the on-bench re-check for the mating part).

## 2. Roborock S5 Caster Wheel — HA00021

**Source link:** Search "HA00021 caster wheel Roborock" on AliExpress/Amazon

| # | What to Measure | Estimate | Unit | Notes |
|---|---|---|---|---|
| 1 | **Overall height** (from floor to top of snap stem) | 52 | mm | Per Amazon WYZBEN "Approx. 2'' (52mm)" |
| 2 | **Overall diameter** (widest point of caster housing) | 46 | mm | Per Amazon WYZBEN "Approx. 1.8'' (46mm)" |
| 3 | **Roller diameter** (the actual rolling ball/roller) | 18 | mm | |
| 4 | **Roller width** (visible width of the roller from side) | 26 | mm | |
| 5 | **Housing body height** (excludes snap stem) | 28 | mm | |
| 6 | **Snap stem diameter** (the part that goes into chassis) | 10 | mm | |
| 7 | **Snap stem length** (from housing top to retention ring) | 12 | mm | |
| 8 | **Retention ring/barbs diameter** | 14 | mm | The widest part of the snap feature |
| 9 | **Housing bottom diameter** (widest part) | 38 | mm | |
| 10 | **Housing top diameter** (at transition to stem) | 28 | mm | |
| 11 | **Housing material** | ABS | — | Per AliExpress listing |

---

## 3. Side Brush Motor — RF-500C-13430

**Compatible part numbers:** RF-500C-13430, RF-500C-13430 DV 7.4V (from remakeai teardown)

| # | What to Measure | Estimate | Unit | Notes |
|---|---|---|---|---|
| 1 | **Motor body diameter** | 24.4 | mm | Standard 500-series DC motor |
| 2 | **Motor body length** (rear cap to gearbox face) | 31.0 | mm | Exclude output shaft |
| 3 | **Gearbox width** | 16.0 | mm | |
| 4 | **Gearbox length** | 18.0 | mm | Along motor axis |
| 5 | **Gearbox height** (from motor axis center) | 20.0 | mm | |
| 6 | **Output shaft diameter** | 3.0 | mm | With D-flat? |
| 7 | **Output shaft exposed length** | 12.0 | mm | |
| 8 | **Mounting ear hole center from motor face** | 22.5 | mm | Distance from front face to first mounting hole |
| 9 | **Mounting hole center-to-center spacing** | 15.0 | mm | Between the two ears |
| 10 | **Mounting ear hole diameter** | 2.5 | mm | |
| 11 | **Terminal gap** (center-to-center of + and −) | 4.5 | mm | |

---

## 4. Main Brush Gearmotor — Roborock S5

**Compatible with:** Roborock S5, S50, S55, S6, S60, S65, and similar.
**AliExpress:** Search "Roborock S5 main brush motor" ($7-11).

| # | What to Measure | Estimate | Unit | Notes |
|---|---|---|---|---|
| 1 | **Motor body diameter** | 29.0 | mm | |
| 2 | **Motor body length** | 34.0 | mm | |
| 3 | **Gearbox width** (perpendicular to motor) | 26.0 | mm | |
| 4 | **Gearbox depth** (along motor axis) | 28.0 | mm | How far gearbox protrudes from motor face |
| 5 | **Gearbox height** (from motor axis to bottom) | 22.0 | mm | |
| 6 | **Output shaft diameter** | 6.0 | mm | |
| 7 | **Output shaft exposed length** | 15.0 | mm | |
| 8 | **Brush socket hex size** (across flats) | 5.5 | mm | If hex socket — the brush adapter |
| 9 | **Socket depth** | 8.0 | mm | How deep the brush inserts |
| 10 | **Mounting flange width** | 32.0 | mm | |
| 11 | **Mounting flange depth** | 26.0 | mm | |
| 12 | **Screw hole span, long direction** | 24.0 | mm | Center-to-center along motor axis |
| 13 | **Screw hole span, short direction** | 18.0 | mm | Center-to-center across motor axis |
| 14 | **Screw hole diameter** | 3.2 | mm | M3 clearance |
| 15 | **Terminal spacing** (center-to-center) | 5.0 | mm | |

---

## 5. Suction Fan Module — Dreame MSD-C-3 / Nidec 20N709U020

**AliExpress:** Search "Dreame L10s fan" ($10-23) for the 6 kPa variant.

| # | What to Measure | Estimate | Unit | Notes |
|---|---|---|---|---|
| 1 | **Housing width** | 60 | mm | Per seller listing: 60×60×30mm |
| 2 | **Housing depth** | 60 | mm | Same |
| 3 | **Housing height** | 30 | mm | Same |
| 4 | **Inlet trumpet diameter** (outer) | 38 | mm | Estimate — the round intake opening |
| 5 | **Inlet trumpet height** (above housing) | 8 | mm | Estimate |
| 6 | **Outlet duct width** | 20 | mm | Estimate — rectangular exhaust nozzle |
| 7 | **Outlet duct height** | 8 | mm | Estimate |
| 8 | **Mounting screw hole pattern** (4 holes) | 48×48 | mm | Estimate — center-to-center |
| 9 | **Screw hole diameter** | 3.2 | mm | Estimate — M3 clearance |
| 10 | **Motor core diameter** (visible bulge on back) | 36 | mm | Estimate |
| 11 | **Motor core height** (protrusion) | 6 | mm | Estimate |
| 12 | **Connector type** | JST XH 3-pin | mm | Estimate |
| 13 | **Cable length** | 80 | mm | Estimate |

### Photo Request
- Top view (inlet trumpet visible)
- Bottom view (motor core bulge)
- Side view (overall height, outlet duct)
- Connector closeup

---

## 6. Peristaltic Water Pump — JYPDM-10 / Generic 6V DC

**AliExpress:** Search "water pump 6V peristaltic" ($3-6).

| # | What to Measure | Estimate | Unit | Notes |
|---|---|---|---|---|
| 1 | **Motor body diameter** | 27.0 | mm | Standard RS-385 class |
| 2 | **Motor body length** | 38.0 | mm | 7mm longer than RS-385 |
| 3 | **Pump head width** | 20.0 | mm | Peristaltic rotor housing |
| 4 | **Pump head length** | 25.0 | mm | Along motor axis |
| 5 | **Pump head height** | 20.0 | mm | |
| 6 | **Overall length** (motor + head) | 63.0 | mm | |
| 7 | **Tube barb outer diameter** | 6.0 | mm | For 2mm ID / 4mm OD tube |
| 8 | **Tube barb inner diameter** | 3.0 | mm | |
| 9 | **Barb center-to-center spacing** | 12.0 | mm | |
| 10 | **Mounting flange width** | 24.0 | mm | If present |
| 11 | **Mounting flange screw hole spacing** | 18.0 | mm | If present |
| 12 | **Screw hole diameter** | 3.0 | mm | If present |
| 13 | **Motor shaft connection** | D-type | — | Check if D-flat or cross-pin |

### Photo Request
- Side view (motor + pump head together)
- Top view (barbs visible)
- Bottom view (mounting flange)
- Connector/wire type

---

## 7. Battery Pack — BRR-2P4S-5200 (14.4V, 5200mAh)

**AliExpress:** Search "BRR-2P4S-5200 battery" ($16-30).

| # | What to Measure | Estimate | Unit | Notes |
|---|---|---|---|---|
| 1 | **Overall length** | 135 | mm | Per Amazon listing. Another source: 137. **VERIFY** |
| 2 | **Overall width** | 38 | mm | Per Amazon listing. Another source: 43. **VERIFY** |
| 3 | **Overall height** | 38 | mm | Per Amazon listing. Another source: 45. **VERIFY** |
| 4 | **Corner radius** | 4 | mm | Estimate |
| 5 | **Connector pin count** | 4 | — | BOM says 4-pin (B+, B-, NTC, sense). Aftermarket often 2-pin. **VERIFY** |
| 6 | **Connector type** | JST? | — | Identify the connector model |
| 7 | **Connector position** (from pack edge) | 20 | mm | Estimate — center of connector body |
| 8 | **Connector body dimensions** | 10×8×8 | mm | Estimate (width × depth × height) |
| 9 | **Cable length** (connector-to-pack entry) | 60 | mm | Estimate |
| 10 | **Screw boss** present at ends? | No | — | Many S5 batteries don't have them |
| 11 | **Pack weight** | 180-230 | g | Estimate (8× 18650 cells + BMS + wrapper) |
| 12 | **Label / part number sticker dimensions** | 70×20 | mm | Estimate |

### Critical Checks
- The three data sources disagree: Amazon says **135×38×38mm**, AliExpress hardware blog says **137×43×45mm**. THIS MUST BE MEASURED on the actual part you receive, as it affects the battery compartment design significantly.
- Confirm the connector pinout: B+, B−, NTC, sense (4-pin) vs just B+, B− (2-pin)
- Measure connector orientation (which face of the pack the cable exits)

---

## 8. Cliff Sensor Module — TCRT5000 (Roomba 500-series)

**BOM:** 4x cliff sensors bundle, $1.50-2.50 each (AliExpress).

| # | What to Measure | Estimate | Unit | Notes |
|---|---|---|---|---|
| 1 | **Module PCB length** | 35 | mm | Estimate — generic MH-sensor module |
| 2 | **Module PCB width** | 10 | mm | Estimate |
| 3 | **Module PCB thickness** | 1.6 | mm | Standard FR4 |
| 4 | **Sensor body L** (TCRT5000) | 10.2 | mm | Vishay datasheet — **confirmed** |
| 5 | **Sensor body W** (TCRT5000) | 5.8 | mm | Vishay datasheet — **confirmed** |
| 6 | **Sensor body H** (TCRT5000) | 7.0 | mm | Vishay datasheet — **confirmed** |
| 7 | **Pin count** | 4 | — | Emitter A/C + Detector C/E |
| 8 | **Pin spacing** | 2.54 | mm | Standard 0.1" header — **VERIFY** |
| 9 | **Mounting hole diameter** | 2.5 | mm | Estimate — M2 clearance |
| 10 | **Mounting hole spacing** (center-to-center) | 29 | mm | Estimate — along board |

### Notes
- Roomba uses these modules at ~20-30° from vertical, mounted near the chassis edge.
- The TCRT5000 bare sensor is **10.2×5.8×7.0mm** (confirmed from Vishay datasheet DS83760).
- Detect range: 0.2-15mm, peak at 2.5mm from sensor face.

---

## 9. Side Brush — 5-Arm (Roborock S5-family)

**BOM:** $2-8 (AliExpress).

| # | What to Measure | Estimate | Unit | Notes |
|---|---|---|---|---|
| 1 | **Overall diameter** (tip-to-tip across opposite arms) | 105 | mm | Per AliExpress wiki: "105mm length" |
| 2 | **Hub diameter** | 28 | mm | Estimate |
| 3 | **Hub thickness** | 5 | mm | Estimate |
| 4 | **Arm width at root** | 8 | mm | Estimate |
| 5 | **Arm width at tip** | 5 | mm | Estimate |
| 6 | **Arm thickness** (material) | 3 | mm | Estimate |
| 7 | **Bristle length** | 12 | mm | Estimate |
| 8 | **Screw hole diameter** (center) | 3.2 | mm | Estimate — M3 clearance |
| 9 | **Screw head diameter** (countersunk) | 7 | mm | Estimate |
| 10 | **Number of arms** | 5 | — | **Confirmed** for S5-family |

### Notes
- BOM also lists 3-arm ($3-9) for S8-family and 2-arm curved ($3-7) for Saros.
  Only the 5-arm is modeled here.
- The brush material is flexible silicone rubber — the arm tips bend during rotation.

---

## 10. Wall Sensor PCB — TSOP38238 + 940nm IR LED

**BOM:** Custom PCB, ~$3 each, 2 units.

| # | What to Measure | Estimate | Unit | Notes |
|---|---|---|---|---|
| 1 | **PCB length** | 20 | mm | Estimate — custom board |
| 2 | **PCB width** | 15 | mm | Estimate |
| 3 | **PCB thickness** | 1.6 | mm | Standard FR4 |
| 4 | **TSOP38238 envelope L (boresight depth)** | 4.8 | mm | Vishay TSOP382/384 datasheet (Doc. 82491 rev 2.1, fetched 2026-08-15) — **confirmed**: Minicast "5.0 W x 6.95 H x 4.8 D". Corrects the old 6.0 mm value |
| 5 | **TSOP38238 envelope W** | 5.0 | mm | Same datasheet — **confirmed** |
| 6 | **TSOP38238 envelope H (total)** | 6.95 | mm | Same datasheet — **confirmed**; overall with leads 8.25 ± 0.3. Corrects the old 4.0 mm value |
| 7 | **IR LED diameter** (TSAL6100 rep.) | 5.0 | mm | Standard 5mm T1¾ |
| 8 | **IR LED height above PCB** | 8.6 | mm | Estimate — including dome and standoff |
| 9 | **Connector type** | JST PH 4-pin | — | Estimate |
| 10 | **Connector pin spacing** | 2.0 | mm | Estimate — JST PH 2.0mm |
| 11 | **Mounting hole diameter** | 2.5 | mm | Estimate — M2 |

---

## 11. OV5647 Camera Module (obstacle avoidance)

**BOM:** 2x OV5647 5MP MIPI, 130° FoV, no IR-cut filter, $6-7 each.

| # | What to Measure | Estimate | Unit | Notes |
|---|---|---|---|---|
| 1 | **PCB length** | 25 | mm | Estimate — Pi Cam v1 proxy |
| 2 | **PCB width** | 24 | mm | Estimate |
| 3 | **PCB thickness** | 1.0 | mm | Estimate — thin PCB |
| 4 | **Sensor package (×, y)** | 8×8 | mm | Estimate |
| 5 | **Sensor package height above PCB** | 4.0 | mm | Estimate |
| 6 | **Lens holder diameter** | 12 | mm | Estimate — M12 thread |
| 7 | **Lens holder height** | 3.0 | mm | Estimate |
| 8 | **Lens barrel height** (total above holder) | 8.0 | mm | Estimate |
| 9 | **FFC connector width** | 10 | mm | Estimate — 16-pin, 0.5mm pitch |
| 10 | **FFC connector depth** | 6 | mm | Estimate |
| 11 | **Mounting hole diameter** | 2.2 | mm | Estimate — M2 |
| 12 | **Mounting hole spacing (×)** | 21 | mm | Estimate — center-to-center lengthwise |
| 13 | **Mounting hole spacing (y)** | 12 | mm | Estimate — center-to-center widthwise |

### Notes
- Physical dimensions vary between OV5647 module vendors. The Pi Camera v1 (OV5647) dimensions
  are used as a proxy. The "night vision" variant (no IR-cut filter) may have a thinner PCB
  and different lens barrel height.
- Field of view: 130° DFoV (BOM spec). This requires a wide-angle M12 lens,
  typically 2.0-2.4mm EFL on 1/4" sensor.

---

## 12. 2D LiDAR — X-WPFTB-V2.6.2 (Dreame / Xiaomi LDS)

**BOM:** 2D LiDAR, PCB mark `X-WPFTB-V2.6.2`, "possibly Camsense", $16-26, fits Dreame L10s family / Xiaomi X10+/S20+.
**Assumed dimension base:** Camsense X1 (official datasheet page, W×D×H = 70×95.3×43.2mm). The two share an identical wire protocol (55 AA 03 08 header, 36-byte packets, 115200 baud) — hardware-confirmed in BVLGARISSK/xiaomi-wpftb-lidar and Vidicon/camsense-X1. I also measured `makerspet/oomwoo-one-cad lib/lidars/camsense_x1.step` this session: 94.6×70.5×43.3mm.

**Source links:**
- Protocol / identity (HW-tested): https://github.com/BVLGARISSK/xiaomi-wpftb-lidar
- Camsense X1 datasheet page: https://www.camsense.cn/en/robot/camsenseX1.html
- Vendor unit listing (black Dreame / orange Xiaomi): ep-mediastore-ab.de (#77339 / #42740)

| # | What to Measure | Estimate | Unit | Notes |
|---|---|---|---|---|
| 1 | **PCB marking** — confirm it reads exactly `X-WPFTB-V2.6.2` | — | — | Identity check; front/back of board |
| 2 | **Overall length** (long axis of housing) | 95.3 | mm | Datasheet 95.3 (Camsense X1 D); measured STEP 94.6 |
| 3 | **Overall width** (short axis) | 70.0 | mm | Datasheet 70.0 (W); measured STEP 70.5 |
| 4 | **Overall height** (base bottom to turret top) | 43.2 | mm | Datasheet 43.2; measured STEP 43.3 |
| 5 | **Turret (rotating head) diameter** | 63.3 | mm | Measured from STEP r=31.65 (approx) |
| 6 | **Turret height above housing** | 21.3 | mm | Estimate (43.2 − housing 22.0) |
| 7 | **Mounting holes on base: count** | 4 | — | Measured from STEP (estimates) |
| 8 | **Mounting hole diameter** (through) | 3.05 | mm | Measured from STEP — M3? |
| 9 | **Mounting hole counterbore dia** | 6.1 | mm | Measured from STEP (approx) |
| 10 | **Mounting hole positions** from scan axis | (22,±31) / (−35,±25) | mm | Measured from STEP (approx) — verify with calipers |
| 11 | **Scan-axis offset** from housing-rect center | −14.25 | mm | Measured from STEP (housing spans −61.55..+33.04) |
| 12 | **Connector type / pitch** | JST GH 1.25mm 4-pin | — | Per upstream SPEC.md + part-specs io-board doc (confirm on unit) |
| 13 | **Wire colors / function** | GND black·brown, DOUT orange, VCC red | — | Per BVLGARISSK HW test (3-wire only) |
| 14 | **Wire length to connector** | 100 | mm | Estimate |
| 15 | **Housing color variant** | black (Dreame) / orange (Xiaomi) | — | Two variants known; record which you bought |

### Notes
- This is the BOM's *primary* LiDAR listing. It is **not** the same physical module as
  the generic Camsense X1 / YDLIDAR / LD19 units already in the one-cad STEP library,
  so this model is not a duplicate — but its geometry is currently an **assumption**:
  if the real X-WPFTB differs from Camsense X1 in envelope, turret diameter, or hole
  pattern, update the SCAD parameter block.
- Sampling spec of the assumed Camsense X1 basis (official page): 0.1–8m range, 360°,
  312±10 RPM, <2W, 50000 lux — electrical/range only, not geometry.

## 13. Main Brush Roller — Roborock S5-family (single roller, code "A1")

**BOM:** Main brush, single roller, rubber + bristles, $5-8. Fits Roborock S4/S4 Max/S5/S5 Max/S50/S55/S6/S6 Pure/MaxV/S60/S65, E2-E5, E20/E25/E35, C10, Xiaomi Mijia.
**Note:** This is the ROLLER, not the gearmotor. The gearmotor (which drives it through a hex socket) is MEASURE-ME §4 `main-brush-gearmotor`. All dims below are estimates from the gearmotor interface + SmartRobotReviews accessory chart (A1 code for S5-family, A2 differs — see model header). **No datasheet exists** (Roborock publishes none) — everything is caliper-verification.

| # | What to Measure | Estimate | Unit | Notes |
|---|---|---|---|---|
| 1 | **Overall length** (drive stub tip → journal tip)  | 176.0 | mm | Must be < brush-bay internal width (~177 est) |
| 2 | **Bristle envelope Ø** (cleaning diameter) | 45.0 | mm | Controls bay floor + brush-cover clearance |
| 3 | **Core body Ø** (under bristles) | 22.0 | mm | |
| 4 | **Drive stub cross-section** (hex vs cross-pin vs triangle) | hex | — | ⚠️ Code A1/A2 differ here — confirm geometry & across-flats |
| 5 | **Drive stub across-flats** | 5.5 | mm | Must match gearmotor socket (MEASURE-ME §4 socket_hex_size) |
| 6 | **Drive stub length** | 12.0 | mm | |
| 7 | **Shoulder disk Ø / thickness** | 16.0 / 2.5 | mm | Limits insertion, seals bay |
| 8 | **Journal Ø** | 10.0 | mm | Fits chassis bushing |
| 9 | **Journal length / tip** | 14.0 / 3.0 | mm | Stepped tip (est) |
| 10 | **Rib count on bristle core** | 8 | — | Pattern representative — confirm |
| 11 | **Fine bristle/rib radial height** | 3.0 | mm | |

### Critical Check
- **Buy & measure the ACTUAL roller** (code A1 for S5/S6/Pure/MaxV-class per the accessory chart). Confirm all of the above with calipers — especially the drive-stub geometry (item 4/5) which is the single fit-critical interface to the already-modeled gearmotor, and which is the most likely place A1/A2 actually differ.

## 14. Mop Disk — OOMWOO printed rotating pad (1 pair, left/right)

**BOM:** "Mop disk | 1 pair | n/a | Left, right | 3D print" (sourced upstream 2026-07-29). The disk mounts on the RS385 mop motor of the BOM "Mop motor assembly" row.
**Anchored interface (datasheet-confirmed, from the sibling mop-assembly branch / Foneacc RS385):** RS385 shaft Ø2.3mm with D-flat (flat width ≈1.8mm), 2× M2.5 face holes @16mm pitch. Everything else below is a DRAFT estimate — tune to your actual pad.

| # | What to Measure | Estimate | Unit | Notes |
|---|---|---|---|---|
| 1 | **Mop pad backing Ø** (your pad) | 98.0 | mm | Disk Ø should ≈ pad backing; cloth is ~ larger |
| 2 | **Pad cloth Ø** (reference) | ~115 | mm | Typical S-class rotating pad overall — verify |
| 3 | **RS385 shaft Ø** | 2.3 | mm | (datasheet) D-bore in hub |
| 4 | **D-flat width across flat** | ~1.8 | mm | (datasheet) chord on bore |
| 5 | **M2.5 hole pitch (c-c)** | 16.0 | mm | (datasheet) must match motor face |
| 6 | **M2.5 clearance hole Ø** | 2.6 | mm | |
| 7 | **Central boss Ø** (pad attachment) | 40.0 | mm | Tune to pad backing hook-loop/stick dia |
| 8 | **Retention slots count / len / wid** | 4 / 18 / 4 | —/mm | Straps or spring clip pass-through |
| 9 | **Rim height / width** | 4.0 / 2.0 | mm | Keeps pad off floor edge — vacuum clearance |
| 10 | **Plate thickness** | 3.0 | mm | |

### Critical Check
- **Dry-fit on the real RS385 motor** using jig `jigs-new/mop-disk-hub-fit.scad` FIRST (prints a shaft+peg replica). Verify the D-bore indexes on the flat and the two M2.5 holes align before printing full disks.
- **Left vs right**: disks are mechanically mirrors; most designs are axisymmetric so no model difference (mirror_side param exists if your retention is directional).
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

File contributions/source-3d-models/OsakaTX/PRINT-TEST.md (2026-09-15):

# PRINT-TEST.md — Fit-Check Jigs for 3D Printing

> These jigs test the fit of sourced parts against the printed chassis.
> Print each jig, insert the corresponding part, and verify clearances.
> Report measured deviations back so the SCAD models can be refined.
>
> **Printer:** Any FDM printer with ~0.2mm layer height.
> **Filament:** PLA or PETG (use PETG if the jig will see mechanical stress).
> **Tolerances:** All SCAD parameters are parametric — adjust the `*_clearance`
> values in the SCAD file to match your printer's tolerance and re-export STL.

---

## Jig 1: Drive Wheel Mounting Bracket Fit Test

**File:** `jigs/drive-wheel-mount-fit.scad`
**Purpose:** Test that the drive wheel mounting bracket screws into the chassis
at the correct position with the right hole spacing.

### Print Instructions
1. Open `drive-wheel.scad` and set `$fn=32` (or higher for smoother curves).
2. Render just the `mounting_bracket()` module — comment out other modules.
3. Export STL and print with 100% infill (structural test).
4. Drill/ream holes if needed — the model uses M3 clearance (~3.2mm).

### Pass Criteria
- All 4 screws (M3) pass through the bracket holes without binding.
- Screw heads sit flush on the bracket surface.
- The bracket aligns with chassis mounting points (once chassis is designed).
- The wheel-drop limit switch cutout (if applicable) has 1-2mm clearance.

### Fail Criteria & Fix
- Holes misaligned → measure actual hole pitch with calipers, update
  `mount_screw_spacing` in SCAD params, re-export.
- Bracket too wide/narrow → adjust `mount_width` or `mount_length`.

---

## Jig 2: Caster Wheel Snap-Fit Pocket

**File:** `jigs/caster-pocket-fit.scad`
**Purpose:** Verify the snap-in pocket for the caster wheel stem.

### Print Instructions
1. Create a negative-pocket version of the caster's snap-stem geometry:
   - Diameter: `stem_diameter + 0.5` (0.5mm clearance)
   - Depth: `overall_height - housing_height` (the embedded portion)
2. Print a small block (40×40×15mm) with this pocket in the center.
3. Snap the caster wheel into the printed pocket.

### Pass Criteria
- The caster wheel snaps into the pocket with moderate resistance (not loose).
- The caster swivels freely once snapped in.
- The caster does not fall out when the block is turned upside-down and shaken gently.

### Fail Criteria & Fix
- Too tight → add 0.2mm to pocket diameter.
- Too loose → reduce pocket diameter by 0.2mm.
- Retention ring doesn't engage → adjust `stem_retain_z` by ±1mm.

---

## Jig 3: Side Brush Motor Mount Check

**File:** `jigs/side-brush-motor-mount.scad`
**Purpose:** Test motor body clearance and mounting ear alignment.

### Print Instructions
1. Create a simple bracket with:
   - A cutout matching the motor body diameter (`motor_body_dia + 1` for clearance)
   - Two holes at `mount_hole_spacing` apart, diameter `mount_ear_hole_dia`
2. Slide the motor into the cutout and insert screws through the ears.

### Pass Criteria
- The motor slides into the cutout without forcing (0.5-1mm clearance).
- Mounting ear holes align with the bracket holes (screws insert freely).
- The gearbox fits within its allocated space without interference.

### Fail Criteria & Fix
- Motor body too loose/tight → adjust `motor_body_dia`.
- Ear holes don't align → verify `mount_ear_center` and `mount_hole_spacing`.
- Gearbox hits chassis wall → adjust `gearbox_width` or `gearbox_height`.

---

## Jig 4: Main Brush Gearmotor Fit Test

**File:** `jigs/main-brush-gearmotor-fit.scad`
**Purpose:** Verify gearmotor mounting flange bolts to chassis and
output shaft aligns with brush roller.

### Print Instructions
1. Create a bracket representing the chassis mounting surface with:
   - 4 screw holes at `flange_hole_span_x` × `flange_hole_span_y`
   - A clearance pocket for the gearbox body
2. Print and bolt the real gearmotor to the bracket.

### Pass Criteria
- All 4 flange screws engage without cross-threading.
- The gearbox body sits within its pocket without interference.
- The output shaft protrudes at the correct height for brush engagement.

### Fail Criteria & Fix
- Holes don't align → measure actual flange, update `flange_hole_span_*`.
- Gearbox hits pocket walls → adjust `gearbox_w`/`gearbox_d`/`gearbox_h`.
- Shaft height wrong → adjust the Z offset in the assembly.

---

## Jig 5: Battery Pack Pocket Fit Test

**File:** `jigs-new/battery-pocket-fit.scad`
**Purpose:** Verify the battery compartment pocket correctly fits a
BRR-2P4S-5200 battery pack.

### Print Instructions
1. Open `jigs-new/battery-pocket-fit.scad` and set the `clearance` variable.
2. Adjust to match your printer's dimensional accuracy:
   - Start with `clearance = 1.0` mm
   - If your printer typically over-extrudes, increase to 1.5 mm
   - If under-extrudes, decrease to 0.6 mm
3. Print with 2 perimeters, 15% infill.
4. Insert the real battery pack into the pocket.

### Pass Criteria
- The battery pack slides into the pocket without forcing.
- There is 0.5-1.5mm play on each side (for thermal expansion + foam padding).
- The connector end protrudes at the correct side.
- The battery can be removed without tools.

### Fail Criteria & Fix
- Too tight → increase `clearance` by 0.2mm, reprint.
- Too loose → decrease `clearance` by 0.2mm.
- Wrong orientation → verify `pack_length` and `pack_width` match actual
  battery dimensions. The pack dimension referencing the BOM is **135mm long**
  per Amazon listing, but another source says **137mm** — measure yours.

---

## Jig 6: Cliff Sensor Mounting Slot Test

**File:** `jigs-new/cliff-sensor-fit.scad`
**Purpose:** Verify TCRT5000 cliff sensor module fits in its chassis slot.

### Print Instructions
1. Open `jigs-new/cliff-sensor-fit.scad` and adjust `clearance` for your printer.
2. Print (no supports needed).
3. Insert the real cliff sensor module into the jig pocket.

### Pass Criteria
- The sensor PCB sits flush in the pocket.
- The sensor body (TCRT5000, 10.2 × 5.8mm) protrudes through the bottom hole.
- The 4 pins are clear (no interference with pocket walls).
- The potentiometer adjust screw (if present) is accessible.

### Fail Criteria & Fix
- PCB too tight → increase `clearance`.
- Sensor body doesn't fit through hole → verify `sensor_body_l` and `sensor_body_w`.

---

## Jig 7: Side Brush Sweep Clearance Template

**File:** `jigs-new/side-brush-clearance.scad`
**Purpose:** Quick visual check that the 5-arm side brush doesn't hit
the chassis or bumper.

### Print Instructions
1. Open `jigs-new/side-brush-clearance.scad` and render.
2. Export STL — prints as a thin ring (1mm thick), essentially the brush
   sweep area.
3. No supports, fast print.

### Pass Criteria
- Place the ring on the chassis at the side brush mount position.
- The ring fits entirely within the chassis perimeter (no overhang).
- The ring clears the main brush opening.
- 10mm margin to nearest chassis protrusion (for bristle flex).

### Fail Criteria & Fix
- Ring overhangs chassis → move side brush mount inward or reduce brush
  effective radius by 5mm.
- Ring overlaps main brush opening → adjust brush position fore/aft.

---

## Jig 8: Wheelbase Alignment Jig

**File:** `jigs/wheelbase-alignment.scad`
**Purpose:** Verify the left and right drive wheels are parallel and
at the correct distance from each other and from the caster.

### Print Instructions
1. Design a rectangular platform that represents the chassis underside.
2. Include:
   - Left and right drive wheel mounting pockets (positions mirror-symmetric)
   - Caster wheel pocket at front center
3. Install real drive wheel modules and caster into the jig.

### Pass Criteria
- Both drive wheel modules seat fully and evenly.
- The distance between wheel contact patches matches the reference URDF.
- All three wheels contact the same plane (no wobble — robot sits flat).
- The wheel-drop switches actuate when wheels are lifted ~8mm.

### Fail Criteria & Fix
- Wheels not parallel → verify mounting bracket orientation in SCAD.
- Robot doesn't sit flat → adjust `tire_diameter` for one or both wheels.
- Caster too high/low → adjust `overall_height` offset.

---

## Jig 9: LiDAR Tower Mount + Turret Clearance

**File:** `jigs-new/lidar-tower-fit.scad`
**Purpose:** Verify the X-WPFTB-V2.6.2 / Camsense X1-class LiDAR's 4 mounting
screws line up with the chassis pattern, and that the rotating turret spins
freely inside the chassis LiDAR tower opening.

### Print Instructions
1. Open `jigs-new/lidar-tower-fit.scad`, tune `clearance` for your printer
   (start 1.0mm) and `hole_clr` for your screws (M3: 0.3mm → 3.35mm holes).
2. Print with 3 perimeters, 20% infill, no supports.
3. Screw the LiDAR module to the jig through the 4 holes (M3, from below).
4. Confirm the turret rotates freely inside the printed tower ring.

### Pass Criteria
- All 4 screws seat without binding (holes align within ±0.5mm).
- The housing overhang vs the footprint recess is ≤ 1mm on every side.
- The turret turns through 360° with light finger force (1–3mm radial play).

### Fail Criteria & Fix
- Screws bind → raise `hole_clr`; holes misaligned → recalibrate the
  `mount_holes` positions of the real module (×/−35, ×/±25 mm are STEP-derived
  estimates) and update both this jig and `x-wpftb-v2.6.2.scad`.
- Turret touches the ring → raise `clearance`; too loose → lower it.
- Housing sits off-center → verify the `−14.25`mm scan-axis offset against the
  real unit (see MEASURE-ME.md §12).

---

## Jig 10: Main Brush Roller Fit Test

**File:** `jigs-new/main-brush-roller-fit.scad`
**Purpose:** Verify the main brush ROLLER (BOM "Main brush", code A1) fits the
brush bay end-to-end and that its two ends mate correctly: the hexagonal drive
stub (∅5.5 across-flats, estimate) must match the gearmotor socket, and the
journal (∅10, estimate) must seat the chassis bushing. Also marks the ∅45
(estimate) bristle envelope the bay must clear.

### Print Instructions
1. Open `jigs-new/main-brush-roller-fit.scad`. Tune clearance values if your
   printer runs large (start with defaults; re-tune after a calibration cube).
2. Print flat with 3 perimeters, 100% infill (it's a dimensional gauge).
3. With the robot upside down and the gearmotor in place, drop the roller's
   drive stub into the jig's hex pocket and seat the journal end in the round
   pocket. (Or place jig in the actual bay if the bay is open.)

### Pass Criteria
- The roller spans the two pockets with ≤ 1.0mm end slop (length verified).
- Drive stub enters the hex pocket without force and indexes flat-to-flat.
- Bristle envelope arc on the jig top fits within the bay floor-to-cover gap.

### Fail Criteria & Fix
- Stub does not enter hex pocket → verify the real stub is hexagonal (A1/A2
  differ!); if triangular/cross-pin, update `main-brush-roller.scad`
  `drive_stub_afl` and the jig's hex pocket, and report to MEASURE-ME §13.
- Length wrong → update `roller_total_len` after caliper measurement.

## Jig 11: Mop Disk Hub Fit Test (RS385)

**File:** `jigs-new/mop-disk-hub-fit.scad`
**Purpose:** Dry-fit verify the printed mop disk's RS385 interface BEFORE
printing full disks: the D-bore (∅2.3 with flat, datasheet) must index on the
motor shaft, and the two M2.5 holes at 16mm pitch (datasheet) must align with
the motor face. The jig prints a POSITIVE replica of the RS385 shaft + mounting
pegs; slide the disk over it.

### Print Instructions
1. Open `jigs-new/mop-disk-hub-fit.scad`. Print flat, 3 perimeters, 100% infill.
2. Slide the printed/actual mop disk (from `mop-disk/mop-disk.scad`) over the
   jig's D-shaped shaft replica and onto the two mounting pegs.
3. Confirm the D-indexing: the disk should not rotate 180° — the flat must
   engage on the +Y flat of the jig shaft.

### Pass Criteria
- Disk D-bore slides fully onto the shaft replica (≤ 0.5mm force) and indexes
  on the flat (cannot be rotated 180° without lifting).
- Both M2.5 holes align with the pegs; disk sits flat on the base plate.
- The printed boss ∅40 (estimate) represents your chosen pad backing — confirm
  the pad dry-fits (adjust `boss_dia` if not).

### Fail Criteria & Fix
- Bore too tight → increase bore clearance in `mop-disk.scad`; too loose →
  decrease. The datasheet shaft is ∅2.3; the D-flat chord position is the
  estimate to verify against the real motor (MEASURE-ME §14).
- Hole pitch off → verify `rs385_hole_pitch` 16.0mm against the actual motor.

## Jig 12: Bumper / Tower Micro Switch Fit Test (SS-5GL-class SPDT)

**File:** `jigs-new/tower-bumper-switch-fit.scad`
**Purpose:** Verify the ACTUAL micro switch (the $0.70 “SPDT or similar” unit)
matches the SS-5GL-class envelope the mount design assumes — body fit, the
3×∅1.6 mounting-hole pattern, and lever sweep. Catches a wrong-form-factor
part BEFORE the tower/bumper housing is finalized.

### Print Instructions
1. Open `jigs-new/tower-bumper-switch-fit.scad`. Print flat, 3 perimeters,
   100% infill (it is a tight-tolerance pocket).
2. Slide the real switch into the cove, plunger/lever side up, lever extending
   toward the guide slot. Full-depth seat, no force.
3. Sight through the three floor pilot holes — they must line up under the
   switch body; verify screw-hole registration by inserting 1.6mm pins through
   the switch and into the pilots.
4. Press the lever down through its travel and confirm it moves inside the
   guide slot without hitting the slot walls.
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

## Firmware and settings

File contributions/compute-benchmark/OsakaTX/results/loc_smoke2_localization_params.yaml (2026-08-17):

slam_toolbox:
  ros__parameters:
    # OOMWOO benchmark params for localization-only mode (ADR-0010). Same
    # frames / resolution / matching policy as slam_toolbox_params.yaml so the
    # numbers stay comparable to the mapping runs (ADR-0002/0007).
    scan_topic: /scan
    odom_frame: odom
    map_frame: map
    base_frame: base_link
    mode: localization       # loads an existing pose graph, does NOT grow it

    # Serialized pose graph to localize against, built by build_and_save_map.sh
    # from the same deterministic scene (slam_toolbox 2.8.5 writes
    # <name>.posegraph + <name>.data; pass the base name, no extension). Per
    # slam_toolbox 2.8.5 source, localization_slam_toolbox_node ALWAYS
    # deserializes a pose graph (LOCALIZE_AT_POSE); map_file_format: pgm only
    # applies in mapping mode. run_slam_localize_bench.sh substitutes the
    # absolute in-container path here before launching.
    map_file_name: /oomwoo/contributions/compute-benchmark/OsakaTX/scripts/../results/localize_anchor_map
    # Robot's true synthetic trajectory start in map coordinates: the deterministic
    # publisher starts at odom (1.5, 0, yaw=pi/2) and slam seeds map=odom at t0,
    # so this IS the robot's start pose used for LOCALIZE_AT_POSE.
    map_start_pose: [1.5, 0.0, 1.5708]

    use_scan_matching: true
    use_scan_barycenter: true
    minimum_travel_distance: 0.05
    minimum_travel_heading: 0.05
    position_covariance_scale: 0.3
    yaw_covariance_scale: 0.3
    transform_publish_period: 0.05
    map_update_interval: 3.0
    resolution: 0.05
    max_laser_range: 12.0
    minimum_time_interval: 0.0
    throttle_scans: 1
    link_match_minimum_response_fine: 0.1
    link_scan_maximum_distance: 3.0
    do_loop_closing: true
    loop_match_minimum_chain_size: 10
    loop_match_maximum_variance_coarse: 3.0
    loop_match_minimum_response_coarse: 0.35
    loop_match_minimum_response_fine: 0.45
    link_search_angle_offset: 0.1
    transform_timeout: 0.2
    tf_buffer_duration: 30.0
    stack_size_to_use: 40000000

    enable_interactive_mode: false

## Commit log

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2026-07-17 part-specs: harmonize carpet SKU and note caster part-number spread
    - Use the full carpet transducer part number (HT-300PLTR1612-1) in the README
    to match the detail file.
    - Add a note in the caster section that replacement listings cite more than
    one Roborock OEM SKU (9.01.1272/1273 vs HA00021) for what appears to be the
    same donor part; the BOM primary remains the Roomba-style iRobot 4624869.
2026-07-17 Sourced obstacle avoidance camera
2026-07-18 Sourced obstacle avoidance range sensor
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2026-07-21 part-specs: STM32G473VCT6 verified specs — correct flash (256KB not 512KB) and HRTIM (absent) errors in oomwoo-io-firmware README
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2026-08-03 source-3d-models/OsakaTX: parametric OpenSCAD models for 4 BOM parts
    Add parametric CAD-as-code models (.scad) and supporting documentation
    for four off-the-shelf BOM parts from the Roborock S5-family donor:
    - Roborock S5 drive wheel assembly (complete: motor, gearbox, tire,
    suspension, mounting bracket, wheel-drop limit switch)
    - Roborock S5 caster wheel HA00021 (omnidirectional snap-in)
    - Side brush motor RF-500C-13430 (500-series DC gearmotor)
    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
    [caster-pocket-fit.scad, caster.scad, drive-wheel-mount-fit.scad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]
2026-08-03 source-3d-models/OsakaTX: import suction fan and peristaltic pump SCAD models from earlier branch
    [peristaltic-pump.scad, suction-fan-module.scad]
2026-08-03 source-3d-models/OsakaTX: add 5 new BOM-part SCAD models + update all docs
    New parametric SCAD models:
    - Battery pack BRR-2P4S-5200 (135x38x38mm, 4S2P Li-ion, datasheet estimate)
    - Cliff sensor TCRT5000 module (datasheet-confirmed sensor body)
    - Side brush 5-arm (105mm diameter envelope model)
    - Wall sensor PCB (TSOP38238 + 940nm IR LED, datasheet-confirmed receiver)
    - OV5647 camera module (obstacle avoidance, 130 deg FoV)
    New fit-check jigs:
    - battery-pocket-fit.scad (battery compartment verification)
    - cliff-sensor-fit.scad (TCRT5000 slot test)
    - side-brush-clearance.scad (sweep area template)
    Documentation updates:
    - MEASURE-ME.md: added sections 7-11 (battery, cliff sensor,
    side brus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
    [battery-pocket-fit.scad, brr-2p4s-5200.scad, cliff-sensor-fit.scad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]
2026-08-05 source-3d-models/OsakaTX: draft parametric model for X-WPFTB-V2.6.2/Dreame 2D LiDAR + fit jig
    - x-wpftb-v2.6.2.scad: Camsense X1-class LDS module draft. Envelope 95.3x70x43.2mm
    from official Camsense X1 datasheet; cross-checked by OCC measurement of the
    makerspet one-cad camsense_x1.step (94.6x70.5x43.3mm). Turret dia 63.3mm and
    4-hole mount pattern measured from that STEP (approx). Connector JST GH 1.25mm
    4-pin per part-specs io-board table. All dims flagged estimate/scanned/datasheet.
    - lidar-tower-fit.scad (jigs-new): print jig to check 4-hole mount alignment and
    turret clearance in the chassis tower.
    - MEASURE-ME.md: new section 12 - X-WPFTB caliper checklist.
    - PRINT-TEST.md: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
    [lidar-tower-fit.scad, x-wpftb-v2.6.2.scad]
2026-08-07 source-3d-models: parametric draft models for main brush roller + mop disk, fit jigs, MEASURE-ME/PRINT-TEST updates
    [main-brush-roller-fit.scad, main-brush-roller.scad, mop-disk-hub-fit.scad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]
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2026-08-08 compute-benchmark: consolidate OsakaTX work + 2026-08-08 reproducibility re-run + ADR-0005 2GB analysis
    [compute_bom.csv, layout_cpp1proc_20260804T193045Z.csv, layout_cpp1proc_20260808T230140Z.csv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]
2026-08-11 compute-benchmark: ADR-0006 measured Nav2 active-goal + recovery (2026-08-11)
    Adds the active-navigation half of the envelope to the OsakaTX compute module:
    a persistent NavigateToPose goal against the same deterministic synthetic
    5 Hz stimulus, re-issued on every bt_navigator abort so the stack stays under
    active navigation demand. Measured (dev-reference x86 container, 45 samples):
    nav2_container 166.5 MiB PSS / 181.5 MiB RSS / 53.7% CPU with 5 spin + 2
    backup recovery behaviors, 11 goal aborts and 27 planner failures inside the
    sampled window -- closes ADR-0005's open item on the dev-reference profile.
    New harness: run_nav2_goal_bench.sh + nav_goal_sender.py + analyze_nav2_goal_csv.py.
    U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
    [nav2_goal_devref_20260811T004809Z.csv, run_matrix.csv]
2026-08-13 compute-benchmark: ADR-0007/0008 measured house-scale SLAM growth + LiDAR-rate sensitivity (2026-08-13)
    ADR-0007: 15m x 15m (2423 sq ft) 480s mapping, 207 samples; slam PSS grows linearly +8.05 MiB/min (R2=0.9995), floor ~42 MiB; map validated 301x301@0.05m.
    ADR-0008: 2.5Hz and 1.25Hz vs 5Hz slam CPU 7.7 and 4.1 vs 12.5-13.7 pct, growth 4.0 and 2.0 vs 5.3-7.7 MiB/min; memory floor unchanged with rate.
    run_slam_bench.sh --hz/--room-half + synthetic_scan_publisher.py --room-half (backward compatible); analyze_slam_trend.py; raw CSVs/logs; RESULTS.md sections 8-9; run_matrix rows (base 793d155).
    [run_matrix.csv, slam_10m_1_25hz_240s_20260813T032039Z.csv, slam_10m_2_5hz_300s_20260813T031537Z.csv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]
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2026-08-17 compute-benchmark: ADR-0010 measured localization-only slam memory is bounded (navigation-phase) - 2026-08-17
    Closes ADR-0007 open question #2 with a measured dataset: slam_toolbox 2.8.5
    localization_slam_toolbox_node (navigation-only phase) against a serialized pose
    graph does NOT grow memory like mapping. Across three 120s dev-reference runs:
    PSS stayed in a 62.6-64.6 MiB band (drift +0.09..+2.14 MiB/min, total <= +1.1 MiB
    per window) vs mapping +5.3-8.05 MiB/min (R2=0.9995) at the same 5 Hz stimulus.
    New reproducible harness: build_and_save_map.sh (anchor pose graph via
    serialize_map -> .posegraph/.data), run_slam_localize_bench.sh (localizer under
    the same deterministic synthetic stream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
    [loc_smoke2_20260817T063643Z.csv, loc_smoke_20260817T062929Z.csv, run_matrix.csv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]
2026-08-17 compute-benchmark: run_matrix - record ADR-0010 commit SHA (2d56f39) in new run rows
    [run_matrix.csv]
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2026-08-23 compute-benchmark: ADR-0013 measured 480s long-horizon localization-only memory (2026-08-23). Answers ADR-0010 open question; no hard plateau; last-half PSS +0.120 MiB/min R2=0.84, whole-window +0.46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
    [slam_localize_5hz_480s_20260823T124356Z.csv]
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2026-08-24 source-3d-models: model CONJOIN CJWP12 robot-side water pump (BOM L64 change); supersedes peristaltic-pump draft
    BOM.md L64 was changed upstream 2026-08-24 (commit 0dfb117 'Use CJWP12
    peristaltic water pump') to name the CONJOIN CJWP12. This grounds the
    robot-side water pump model to that named part:
    - NEW cjwp12-water-pump/cjwp12-water-pump.scad: parametric draft, two
    sub-variants (AA05A5 / AB05A1), pump-head 21x12 mm cross-section from the
    Conjoin official product pages (conjoinfluid.com CJWP12-AA/AB, fetched this
    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
    [battery-pocket-fit.scad, brr-2p4s-5200.scad, carpet-sensor-fit.scad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]
2026-08-24 io-board-interface: Aug 24 cross-check + signal-ownership corrections
    - spec_crosscheck_20260824: first pcb-repo movement since Aug 15
    (commit c70c9447 "Fix edge cut; no-CM STEP", 2026-08-23). Verified
    interface no-drift for CPU<->MCU scope (root hierarchy, SPEC.md sha1,
    CM5-GPIO UART2/UART4/PMIC surface, MCU sheet all unchanged). Found the
    ONLY functional net change: V-MOTORS-EN converted to hierarchical label
    in BMS-SYSTEM-POWER (connectivity fix; net name unchanged -> OSK-024
    watchdog pair unaffected). New firmware RFC (oomwoo-io-firmware 0ad93b8e)
    independently confirms STM32G473VCT6 + G0->G4 migration (OSK-018);
    OSK-027 (UART5 DMA) still open. Flagged rename of stale
    S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
2026-09-07 source-3d-models: rebuild drive-wheel CAD on the merged IKsares measurements
    drive-wheel.scad v2: 65.36:1 counted train, helical stage-1 (mn 0.5,
    beta 27.5 mid-hypothesis, centre-distance test documented), motor
    27.5x34+10.3 shaft 2.2, wheel 71.5, harness 7-way 1.5 mm-pitch. Old
    all-estimate sketch superseded in place. MEASURE-ME §1 rewritten to the
    post-merge gate list (centre distance is now the key reading) + JST ZH
    1.5 gauge jig referenced; dims-tally audit promised in header.
    [drive-wheel.scad]
2026-09-07 source-3d-models: carry forward the aug24 unmerged module state
    The 51 files from branch source-3d-models-osakatex-aug24 (all pumps,
    sensors, fans, jigs, PRINT-TEST, module README) ride on this branch so it
    stands alone against current main; wheel model + MEASURE-ME §1 come from
    the previous commit (2026-09-06 rebuild), not the aug24 snapshots.
    [battery-pocket-fit.scad, brr-2p4s-5200.scad, carpet-sensor-fit.scad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]
2026-09-07 source-3d-models: jigs 22/23 (wheel-harness ZH pitch, dock-fan class rings) + dims-tally audit
    Jig 22: 7-way plug ZH 1.5 vs PH 2.0 slot rows -- on-bench re-check of the
    IKsares-measured 9.0/6=1.5 mm pitch. Jig 23: 65mm-class GO/MIN rings per
    BOM auto-empty fan row. PRINT-TEST sections with pass/fail tables pointed
    at MEASURE-ME rows. dims-tally.py: first run shows only the new
    drive-wheel model+igan carry [M]-tags; all legacy models are
    all-(estimate) -- a true statement this tool now keeps checkable.
    [drive-wheel-plug-and-fan-class-gauge.scad]
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2026-09-08 compute-benchmark: ADR-0014 measured - lifelong mapping memory plateau is noise-robust; CPU is the noise-sensitive axis
    - synthetic_scan_publisher.py: --noise SIGMA_M deterministic per-scan range
    noise (stateless seeding; validated paired-delta sd 0.07065 vs 0.07021
    theory at 0.05... see ADR-0014); sigma 0 path bit-identical to history
    - run_slam_bench.sh / run_slam_lifelong_bench.sh: --noise passthrough;
    async harness gains the map-check + snapshot gate (pre-teardown)
    - 5 measured 480s stages @5Hz 15m house (async 0.00/0.05, lifelong
    0.00/0.05/0.15): lifelong last-half PSS slopes +0.432/+0.622/+0.513 MiB/min
    vs async +7.694/+7.673 (ADR-0007 growth term confirmed noise-robust);
    l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
    [run_matrix.csv, slam15m_noise_n000_async_20260908T144713Z.csv, slam15m_noise_n000_lifelong_20260908T150401Z.csv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]
2026-09-08 compute-benchmark: run_matrix - record ADR-0014 runs (data commit 910dfec) and map-snapshot provenance
    [run_matrix.csv]
2026-09-10 compute-benchmark: ADR-0015 measured - Nav2+slam as ONE system; async sum climbs +8.3 MiB/min, lifelong steady ~293 MiB flat
    run_nav2_slam_combo_bench.sh + analyze_combo_bench.py; combo/ artifacts incl attempt1 debug set; run_matrix +3 rows; RESULTS section 16
    [attempt1_lifelong_20260910T184017Z.csv, combo_async_devref_20260910T180755Z.csv, combo_lifelong_devref_20260910T185130Z.csv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]
2026-09-11 source-3d-models: dock auto-empty fan rebuilt candidate-parametric (Nidec BL-V55 / BG26 presets) + candidate-ID jig 19C
    [dock-auto-empty-fan.scad, dock-fan-candidate-id-gauge.scad]
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

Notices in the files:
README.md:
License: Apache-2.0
